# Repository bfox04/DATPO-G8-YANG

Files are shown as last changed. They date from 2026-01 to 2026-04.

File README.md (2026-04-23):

# DATPO — Dual Airfoil Test Platform Octopus (Group 8, Yang)

Capstone project. A motorized dual-airfoil rig for wind tunnel testing, controlled over USB or Bluetooth serial with a browser-based GUI. Controls stagger (X), gap (Y), and angle of attack (ZA bot, ZB top) for both airfoils independently.

---

## Hardware

**Controller:** BTT Octopus V1.0 (STM32F446, 180MHz)

**Motors:** 8× NEMA 17 steppers (17HS19-2004D-E1K, 2A, 1.8°/step)
**Drivers:** TMC2209 in step/dir mode, 8 microsteps

| Axis | Motors | Pitch / Ratio | Limit |
|---|---|---|---|
| X (stagger) | M0, M1 | 5mm/rev | ±415mm |
| Y (gap) | M2–M5 | 2mm/rev | ±225mm |
| ZA (AoA bot)| M6 | 5.1975× gear ratio | ±20° |
| ZB (AoA top)| M7 | 5.1975× gear ratio | ±20° |

**Encoders:** 4× quadrature encoders (1000 PPR / 4000 CPR) on E0–E3, covering X left/right and Y left/right. Used for sync checking only — not closed-loop. E6/E7 slots in the GUI mirror ZA/ZB (see Known Issues).

**Fan:** PA8, on by default, toggle with `FAN` command.

---

## Firmware

Built with PlatformIO (Arduino framework). Source is `FIRMWARE/src/WORKING_MAIN.cpp`.

**You'll need:**
- VS Code + PlatformIO extension
- Serial Monitor extension (or use the GUI)
- Target board: `btt_octopus_f446`

**Key behaviors:**
- Accepts commands over USB (`Serial`) or Bluetooth (`Serial1`, 115200 baud both)
- Broadcasts `POS:` telemetry lines after every move and on `POSITIONS` — this is what the GUI parses
- X and Y encoder pairs are compared each loop cycle; if divergence exceeds 5mm, all motors stop and it auto-enters jog mode for realignment
- Motion is open-loop for ZA/ZB (no encoder feedback on AoA axes)

---

## GUI

`GUI/ENCODER_GUI.html` — open in Chrome, uses Web Serial API. No install needed.

`GUI/WORKING_GUI.html` is the older version, kept for reference.

---

## Serial Command Reference

| Command | Description |
|---|---|
| `X[mm]` | Move X axis to position (e.g. `X50`) |
| `Y[mm]` | Move Y axis to position |
| `ZA[deg]` | Move AoA bot to angle (e.g. `ZA-5`) |
| `ZB[deg]` | Move AoA top to angle |
| `HOME` | Move all axes to zero |
| `POSITIONS` | Print current positions + POS: line |
| `ZERO` | Enter jog & zero mode |
| `ESTOP` | Immediate stop, clears alarm |
| `RESUME` | Clear sync alarm |
| `FAN` | Toggle fan |
| `COMMANDS` | Print command list |

**In jog/zero mode:** `X+` `X-` `Y+` `Y-` `YL+` `YL-` `YR+` `YR-` `ZA+` `ZA-` `ZB+` `ZB-`, individual motors `M0+` through `M7+/-`, `STEP[size]` (0.1/0.25/0.5/1.0/2.0/3.0), `SET` to zero, `EXIT` to leave.

---

## Known Issues & Lessons Learned

**AMT25 absolute encoders on ZA/ZB were attempted and abandoned.** The hardware and firmware implementation were correct, but we got unbeatable EMI from the motor cabling corrupting the encoder signal. The DIAG pins on the Octopus (used as encoder inputs) are physically adjacent to motor driver lines — not great for signal integrity.

**Encoder sync alarm is functional but conservative.** 5mm threshold works well in practice. If you're getting nuisance trips, check that encoder cables are routed away from motor wiring.

**ZA/ZB home angles are not set.** `ZA_HOME_ANGLE` and `ZB_HOME_ANGLE` in firmware are both 0.0 — the rig assumes the airfoils start at 0° on power-up. If you add hard stops, measure and set these.

---

## TODO (Next Group)

- [ ] **Integrate AMT25 absolute encoders on ZA/ZB** — the big one. Hardware and firmware were working; the blocker was EMI. Suggested approach: use shielded cable for encoder lines, route far from motor cabling, or add an external encoder interface board to put distance between the noisy motor drivers and the encoder signal path. The AMT25 uses SSI/SPI — an isolator IC between the Octopus and encoders would likely fix it. This would give true closed-loop AoA control, which is the main thing missing.
- [ ] Measure and set physical hard-stop home angles for ZA/ZB in firmware
- [ ] Add software travel limits as a safety net (currently relies on operator not sending out-of-range commands)
- [ ] Y axis has 4 motors (M2–M5) but only 2 encoders — E2 and E3 cover left and right sides. Consider adding encoders on the far pair if racking becomes an issue.

---

## Repo Layout

```
DATPO-G8-YANG/
├── FIRMWARE/       main firmware (PlatformIO project)
├── GUI/            browser-based serial GUI (Chrome)
├── CAD/            airfoil and zero-tool 3D files
├── DOCS/           manuals, datasheets, master reference, capstone poster
├── PINOUTS/        board and driver pinout images
├── MEDIA/          demo videos
├── ARCHIVE/        old firmware builds
└── TODO.txt        running notes
```

Full consolidated hardware reference (board pinout, driver config, motor specs) is in `DOCS/PROJECT_MASTER_REFERENCE.md`.

Claude was used as a major assistant for writing software.

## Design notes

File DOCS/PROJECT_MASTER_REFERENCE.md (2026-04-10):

# Project Master Reference Document
## Consolidated from: Board Pinout, Board Manual, TMC2209 Pinout, TMC2209 Manual, Motor/Encoder Datasheet

---

# 1. BTT OCTOPUS V1.0 — MOTOR DRIVER PIN MAPPING

| Driver | EN | STEP | DIR  | CS |
|---|---|---|---|---|
| DRIVER0  | PF14 | PF13 | PF12 | PC4  |
| DRIVER1  | PF15 | PG0  | PG1  | PD11 |
| DRIVER2  | PG5  | PF11 | PG3  | PC6  |
| DRIVER3  | PA0  | PG4  | PC1  | PC7  |
| DRIVER4  | PG2  | PF9  | PF10 | PF2  |
| DRIVER5  | PF1  | PC13 | PF0  | PE4  |
| DRIVER6  | PD4  | PE2  | PE3  | PE1  |
| DRIVER7  | PE0  | PE6  | PA14 | PD3  |

Motor-SPI Bus:
- MOSI: PA7
- MISO: PA6
- SCK: PA5

---

# 2. BTT OCTOPUS V1.0 — FULL BOARD PINOUT

## Heaters
| Heater | Voltage | Signal Pin |
|---|---|---|
| HE0 | 24V | PA2 |
| HE1 | 24V | PA3 |
| HE2 | 24V | PB10 |
| HE3 | 24V | PB11 |

## Bed Heater
- BED Power: VBI / GND
- BED-OUT: VBO / PA1

## Temperature Sensors
| Sensor | GND | Signal |
|---|-----|---|
| TB | GND | PF3 |
| T0 | GND | PF4 |
| T1 | GND | PF5 |
| T2 | GND | PF6 |
| T3 | GND | PF7 |

## Fans (PWM)
| Fan | Voltage Pin | Signal Pin |
|---|---|---|
| FAN0  | VFAN0 | PA8 |
| FAN1  | VFAN1 | PE5 |
| FAN2  | VFAN2 | PD12 |
| FAN3  | VFAN3 | PD13 |
| FAN4  | VFAN4 | PD14 |
| FAN5  | VFAN5 | PD15 |
| FAN6  | VFAN6 | GND (always on) |
| FAN7  | VFAN7 | GND (always on) |

Fan voltage selectable per fan: Vin (24V), 12V, or 5V via jumpers.

## DIAG Pins (StallGuard)
| DIAG  | 5V  | GND | Signal |
|---|-----|-----|---|
| DIAG0 | 5V  | GND | PG6 |
| DIAG1 | 5V  | GND | PG9 |
| DIAG2 | 5V  | GND | PG10 |
| DIAG3 | 5V  | GND | PG11 |
| DIAG4 | 5V  | GND | PG12 |
| DIAG5 | 5V  | GND | PG13 |
| DIAG6 | 5V  | GND | PG14 |
| DIAG7 | 5V  | GND | PG15 |

## I2C & EEPROM
- SCL: PB8
- SDA: PB9
- Onboard 32K EEPROM (AT24C32)

## SPI Expansion Header
- 3.3V, PB5 (MOSI), PA15 (CS), PB4 (MISO), PB3 (SCK), GND

## USB-A Port
- GND, PB15, PB14, 5V

## Raspberry Pi Header
- 5V, GND (multiple), PD6(RX), PD5(TX), 5V

## TFT Header
- RST, PA10(RX), PA9(TX), GND, 5V

## BL Touch Header
- GND, 5V, PB6, PB7, GND

## EXP1 (Display)
- PE8, PE9, PE12, PE14, GND
- PE7, PE10, PE13, PE15, 5V

## EXP2 (Display)
- PA6, PB1, PB2, PC15, RST
- PA5, PA4, PA7, GND, PC5

## PS ON (Power Supply Control)
- PE11, GND

## SENSOR (Probe)
- VS, GND, PB7

## CAN Bus (RJ11)
- NC, CAN_L, CAN_H, NC
- RX: PD0, TX: PD1

## SDIO-MicroSD
- D0: PC8, D1: PC9, D2: PC10, D3: PC11, CLK: PC12, DET: PC14, CMD: PD2

## SPI3 Expansion Header
Row 1: 3.3V, PC3, PC2, PB13, NC, PG8, NC, PG7 (MOSI, MISO, SCK)
Row 2: GND, PB12, NC, PD7, PD10, NC, PD8, PD9 (CS, TX, RX)

## RGB LED
- GND, PB0, 5V

## PT100 Interface
- PF8, PT100_P, PT100_N

## Power Detection
- PWR-DET: 3.3V, GND, PC0

---

# 3. BTT OCTOPUS V1.0 — BOARD MANUAL SUMMARY

## Key Specs
- MCU: STM32F446ZET6 (ARM Cortex-M4, 180MHz)
- Board size: 160mm x 100mm (mounting holes: 150mm x 90mm)
- Supports Klipper and Marlin firmware
- Recommended input: DC 24V (12V supported on motor and bed rails only; logic must be >14.1V)
- Built-in regulators: 12V (4A), 5V (8A), 3.3V (1A)
- Up to 8 stepper drivers, 9 stepper outputs (MOTOR2 has dual output for parallel Z)
- 4 hotend heaters, 1 heated bed (up to 300W, use external MOSFET for higher)
- 6 PWM fans + 2 always-on fans, individually voltage-selectable (Vin/12V/5V)
- Flyback protection on all PWM fan ports
- 6 endstop inputs, 2 filament runout inputs
- USB-C (virtual serial), UART, SPI connections to Raspberry Pi
- Onboard 32K EEPROM (AT24C32)
- BL Touch support, dedicated PROBE port (optocoupler-protected, no BAT85 needed)
- CAN Bus via RJ11 (6P6C)
- StallGuard support for sensorless homing (TMC drivers)
- SPI expansion port (for MAX31865, etc.)
- DIY PT100 interface (requires user-soldered INA826AIDR amplifier, SOP-8)
- Thermistor inputs protected up to Vin; unused inputs usable as GPIO
- WiFi interface for ESP8266 modules
- RGB LED interface
- SD card firmware update (firmware.bin → FIRMWARE.CUR)
- Supports DFU mode firmware update (overwrites bootloader — not recommended for novices)

## Power Wiring
Three separate power inputs (common ground):
1. Motherboard power (must be >14.1V for logic regulators)
2. Motor power (12V or 24V)
3. Bed heater power (12V or 24V)

## Stepper Driver Modes

### Step/Dir Mode
Jumper layout beneath each driver (simplified):
```
Row 1 (top):    0V     0V     0V     0V
Row 2 (middle): RST    MS3/2  MS2/1  MS1/0
Row 3 (bottom): SLP    3.3V   3.3V   3.3V
```
- Jumper top-to-middle: sets MS pin to 0V (LOW)
- Jumper middle-to-bottom: sets MS pin to 3.3V (HIGH)
- First column: connects SLP to RST (required for A4988/DRV8825)
- Note: Using non-16 microstepping in step/dir mode prevents SPI mode on other drivers (shared pins)

### UART Mode
Single jumper on the designated UART position beneath the driver.

### SPI Mode
Specific jumper configuration beneath the driver for SPI communication.

## StallGuard / Sensorless Homing
DIAG jumpers connect driver diagnostic output to endstop inputs. Located in a dedicated jumper block on the board.

## Probe Port
- Internally protected via optocoupler (no BAT85 diode needed)
- NPN probes: add external 4K7 pull-up between probe V+ and signal
- PNP probes: connect directly
- Must enable internal pull-down resistor on probe input pin in firmware

## Klipper Firmware Settings
When compiling Klipper, use settings to preserve factory bootloader:
- Micro-controller: STM32
- Processor: STM32F446
- Bootloader offset: 32KiB
- Communication: USB on PA11/PA12

## Precautions
1. Never work on board with power applied
2. Double-check all jumpers/wiring before powering on
3. Heated bed max 300W (use external MOSFET for more)
4. Always reference PINS.pdf for connections
5. SD card firmware update recommended over DFU
6. Early production silkscreen errors on: Fan polarity, SPI3 header, Raspberry Pi UART header

---

# 4. BIGTREETECH TMC2209 V1.2 — SCHEMATIC/PINOUT

## IC Pin Connections (TMC2209 chip — U1)
| Pin # | Name | Function |
|---|---|---|
| 2 | ENN | Enable (active low) |
| 16 | STEP | Step pulse input |
| 19 | DIR | Direction input |
| 11 | DIAG | Diagnostic/StallGuard output |
| 12 | INDEX | Configurable index output |
| 9 | MS1 | Microstep config / UART addr |
| 10 | MS2 | Microstep config / UART addr |
| 9 | MS1_AD0 | Address bit 0 (UART mode) |
| 10 | MS2_AD1 | Address bit 1 (UART mode) |
| 13 | CLK | Clock input |
| 14 | PDN_UART  | UART interface |
| 17 | VREF | Analog reference for current |
| 15 | VCC_IO | Logic supply voltage |
| 8 | 5VOUT | Internal 5V regulator output |
| 22 | VS | Motor supply voltage |
| 28 | VS | Motor supply voltage |
| 6 | VCP | Charge pump capacitor |
| 5 | CPI | Charge pump input |
| 4 | CPO | Charge pump output |
| 1 | OB2 | Output bridge B2 |
| 26 | OB1 | Output bridge B1 |
| 24 | OA2 | Output bridge A2 |
| 21 | OA1 | Output bridge A1 |
| 23 | BRA | Bridge sense resistor A |
| 27 | BRB | Bridge sense resistor B |
| 7 | SPREAD | SpreadCycle/StealthChop select |
| 20 | STDBY | Standby |

## Module Connector Pinout (J1 and J2 headers on module)
### J1 (Left side, active pins):
| Pin | Name | Function |
|-----|---|---|
| 1 | EN | Enable |
| 2 | MS1 | Microstep setting |
| 3 | MS2 | Microstep setting |
| 4 | PDN_UART | UART communication  |
| 5 | PDN_UART | UART communication  |
| 6 | CLK | Clock |
| 7 | STEP | Step pulse input |
| 8 | DIR | Direction input |

### J2 (Right side, motor/power):
| Pin | Name | Function |
|-----|---|---|
| 1 | VM | Motor voltage |
| 2 | GND | Ground |
| 3 | A2 | Motor Phase A |
| 4 | A1 | Motor Phase A |
| 5 | B1 | Motor Phase B |
| 6 | B2 | Motor Phase B |
| 7 | VCC_IO | Logic voltage |
| 8 | GND | Ground |

### Additional Module Pins:
- DIAG: Diagnostic/StallGuard output (directly accessible via header)
- VREF: Analog reference (accessible via potentiometer)
- INDEX: Configurable index pulse output

## SPREAD Pin Configuration
| Mode | SPREAD |
|---|---|
| StealthChop | 0 (LOW) |
| SpreadCycle | 1 (HIGH) |

## Microstep Configuration
| MS1 | MS2 | Microstep |
|-----|-----|---|
| 0 | 0 | 1/8 |
| 1 | 0 | 1/2 |
| 0 | 1 | 1/4 |
| 1 | 1 | 1/16 |

Note: MicroPlyer interpolation provides up to 256 microsteps regardless of MS pin setting.

## Vref / Current Setting
- Vref range: 0.2V — 2.2V
- Factory default Vref: 1.2V ±0.1V
- Factory default current: 0.9A
- Clockwise potentiometer rotation: decreases Vref → decreases current
- Counter-clockwise rotation: increases Vref → increases current

## Key External Components (from schematic)
- C2: 100nF/50V (VDD decoupling)
- C5: 4.7nF (GND)
- C1: 1nF/50V, C3/C4: 100nF/50V (VS decoupling)
- C6: 100nF, C7: 22nF/50V (charge pump)
- R1: 20K (EN pull-up)
- R3: 100K (CLK), R4: 100K (PDN_UART)
- R5: (VREF setting)
- R6: 20K, R7: 20K (address resistors)
- 0R11 sense resistors on BRA/BRB

---

# 5. BIGTREETECH TMC2209 V1.2 — DRIVER MODULE MANUAL

## Product Specs
- Continuous drive current: 2A RMS
- Peak current: 2.8A
- Voltage range: 4.75V — 28V DC
- Module size: 15.24mm x 20.32mm
- Operating modes: STEP/DIR or UART
- Microstep settings: 2, 4, 8, 16 (interpolated up to 256)

## Technologies
- SpreadCycle: high-dynamic motor control chopper
- StealthChop2: ultra-quiet operation
- MicroPlyer: microstep interpolation to 256
- StallGuard4: stall/locked-motor detection
- CoolStep: dynamic current control (up to 75% energy savings)

## UART Mode Setup
- Factory default: UART connected to pin 4 (PDN_UART on left header)
- To use pin 5 as UART: remove resistor and re-solder to alternate pads

## StealthChop vs SpreadCycle
- Factory default: StealthChop (mute/quiet mode)
- To switch to SpreadCycle (anti-shake mode): remove resistor and re-solder to alternate pads

## Safety Precautions
1. Disconnect power before installing/removing driver
2. Confirm driver orientation before insertion (prevent reverse insertion)
3. Verify wiring sequence and I/O connections
4. Do not hot-swap driver modules
5. Ensure heatsink does not short any pins
6. Handle with ESD precautions
7. Always provide heat dissipation (heatsink + fan recommended)

---

# 6. STEPPER MOTOR — 17HS19-2004D-E1K (StepperOnline)

## Motor Specifications
| Parameter | Value |
|---|---|
| Connection | Bipolar |
| Amps/Phase | 2.00A |
| Resistance/Phase @ 25°C | 1.10Ω ±10% |
| Inductance/Phase @ 1kHz | 1.70mH ±20% |
| Holding Torque | 0.52 Nm [4.60 lb-in] |
| Step Angle | 1.8° |
| Step Accuracy (non-accumulative) | ±5.00% |
| Rotor Inertia | 82.00 g·cm² |
| Weight | 0.50 kg [1.10 lb] |
| Ambient Temperature | -10°C to 50°C [14°F–122°F] |
| Insulation Class | B (130°C / 266°F) |
| Temperature Rise | MAX 80°C |

## Motor Wiring (Bipolar)
| Pin | Bipolar | Lead Color | Winding |
|-----|---|---|---|
| 1 | A+ | BLK (Black)| A+ |
| 2 | A- | GRN (Green)| A- |
| 3 | B+ | RED | B+ |
| 4 | B- | BLU (Blue) | B- |

## Motor Cable
- TRVV 4×0.2² black servo towline cable
- Length: 500±10mm
- Heat shrink tube at motor junction

## Encoder Specifications
- Resolution: 1000 PPR (4000 CPR with quadrature)
- Cable: TRVVP 6×0.15² black shielded wire
- Cable length: 500±10mm

## Encoder Wiring
| Lead Color | Description |
|---|---|
| RED | VCC (power) |
| WHT (White)| GND |
| BLK (Black)| EA+ (Encoder A+) |
| BLU (Blue) | EA- (Encoder A-) |
| YEL (Yellow)| EB+ (Encoder B+) |
| GRN (Green)| EB- (Encoder B-) |

## Mechanical Dimensions (mm)
- Body: 42.3 MAX × 42.3 MAX (NEMA 17)
- Flange: 31±0.1 × 31±0.1
- Mounting holes: 4× M3, depth 4.5mm
- Shaft diameter: Ø5 (0 / -0.012mm tolerance)
- Shaft length: 24±1mm (from flange)
- Total length with encoder: 68±1mm
- Shaft flat: 15±0.2mm from flange, width 2mm
- Rear shaft extension: 9.6mm, width 32mm

## Full Step Sequence (2-phase, facing mounting end)
| Step | A+ | B+ | A- | B- | Direction |
|---|----|----|----|----|---|
| 1 | +  | +  | -  | -  | CCW |
| 2 | -  | +  | +  | -  | ↓ |
| 3 | -  | -  | +  | +  | ↓ |
| 4 | +  | -  | -  | +  | CW |

## Operating Limits
- Dynamic axial load: 10N max
- Dynamic radial load @ shaft 20mm: 21N max
- TMBF: 6000h or more @ 24V/300RPM
- Insulation resistance: 100 MΩ (normal temp/humidity)
- Dielectric strength: 500VAC for 1 min (between coils and case)

---

# 7. APPENDIX — COMMON DRIVER MICROSTEPPING TABLES

## A4988 (max 16 microsteps, 35V 2A)
| MS1 | MS2 | MS3 | Microstep  |
|-----|-----|-----|---|
| L | L | L | Full Step  |
| H | L | L | 1/2 |
| L | H | L | 1/4 |
| H | H | L | 1/8 |
| H | H | H | 1/16 |

Current formula: Imax = Vref / (8 × Rs), Rs = 0.1Ω

## LV8729 (max 128 microsteps, 36V 1.8A)
| MD3 | MD2 | MD1 | Microstep  |
|-----|-----|-----|---|
| L | L | L | Full Step  |
| L | L | H | 1/2 |
| L | H | L | 1/4 |
| L | H | H | 1/8 |
| H | L | L | 1/16 |
| H | L | H | 1/32 |
| H | H | L | 1/64 |
| H | H | H | 1/128 |

Current formula: Iout = (Vref / 5) / Rf1, Rs = 0.22Ω

## DRV8825 (max 32 microsteps, 8.2V–45V 2.5A @ 24V T=25°C)
| MODE2 | MODE1 | MODE0 | Microstep  |
|---|---|---|---|
| L | L | L | Full Step  |
| L | L | H | 1/2 |
| L | H | L | 1/4 |
| L | H | H | 1/8 |
| H | L | L | 1/16 |
| H | L | H | 1/32 |
| H | H | L | 1/32 |
| H | H | H | 1/32 |

Current formula: I_CHOP = V_REFX / (5 × R_ISENSE), Rs = 0.1Ω

## TMC2209 (on module, for reference)
| MS1 | MS2 | Microstep |
|-----|-----|---|
| 0 | 0 | 1/8 |
| 1 | 0 | 1/2 |
| 0 | 1 | 1/4 |
| 1 | 1 | 1/16 |

All modes interpolated to 256 microsteps via MicroPlyer.

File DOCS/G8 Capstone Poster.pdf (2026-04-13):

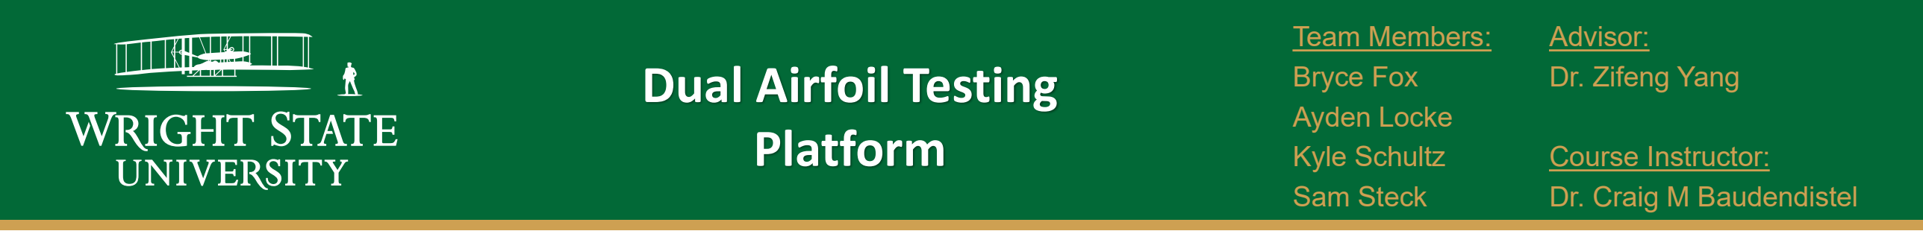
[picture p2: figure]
Dual Airfoil Testing Platform; Team Members:; Bryce Fox; Ayden Locke; Kyle Schultz; Sam Steck; Advisor:; Dr. Zifeng Yang; Course Instructor:; Dr. Craig M Baudendistel
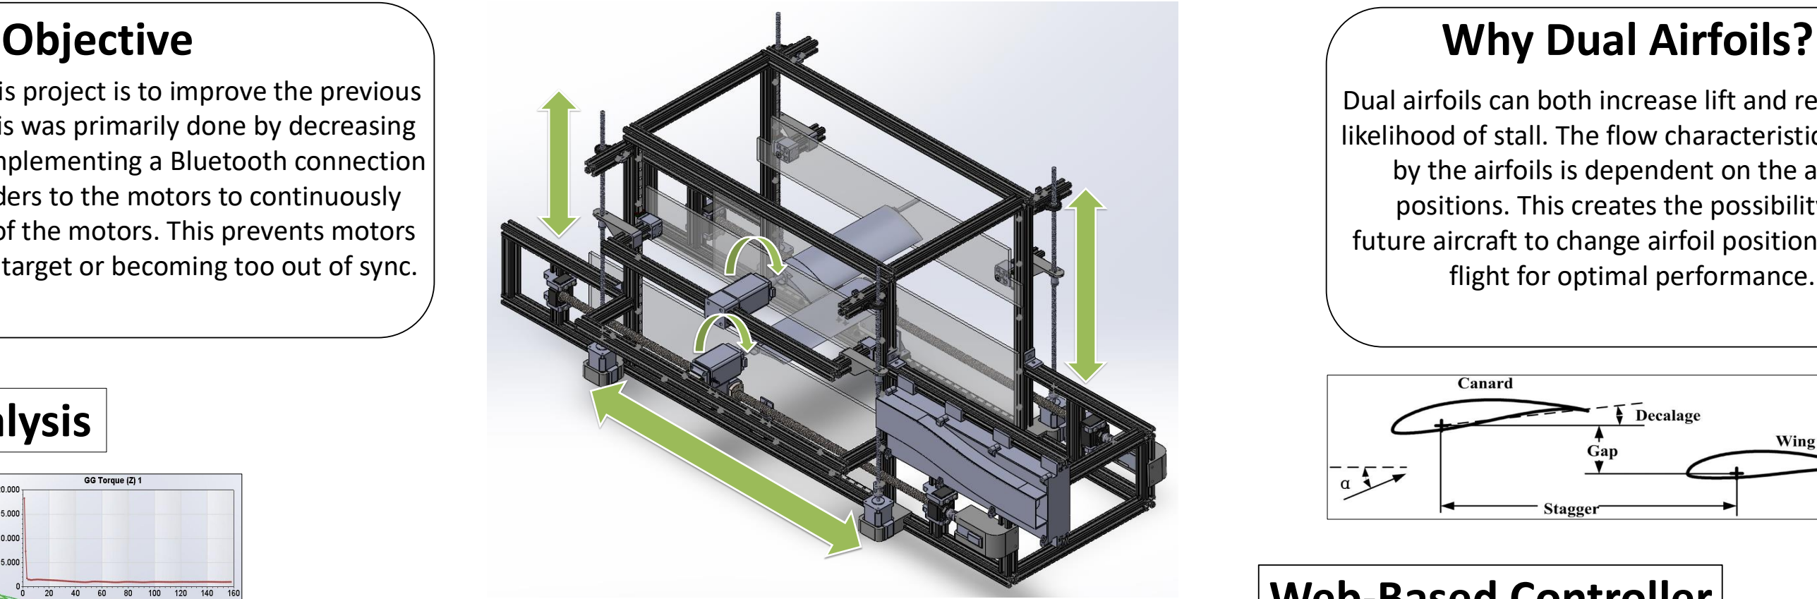
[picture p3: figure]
Objective; Why Dual Airfoils?; flight for optimal performance.

The objective of this project is to improve the previous group's design. This was primarily done by decreasing the lose wires by implementing a Bluetooth connection and adding encoders to the motors to continuously read the position of the motors. This prevents motors from missing their target or becoming too out of sync.

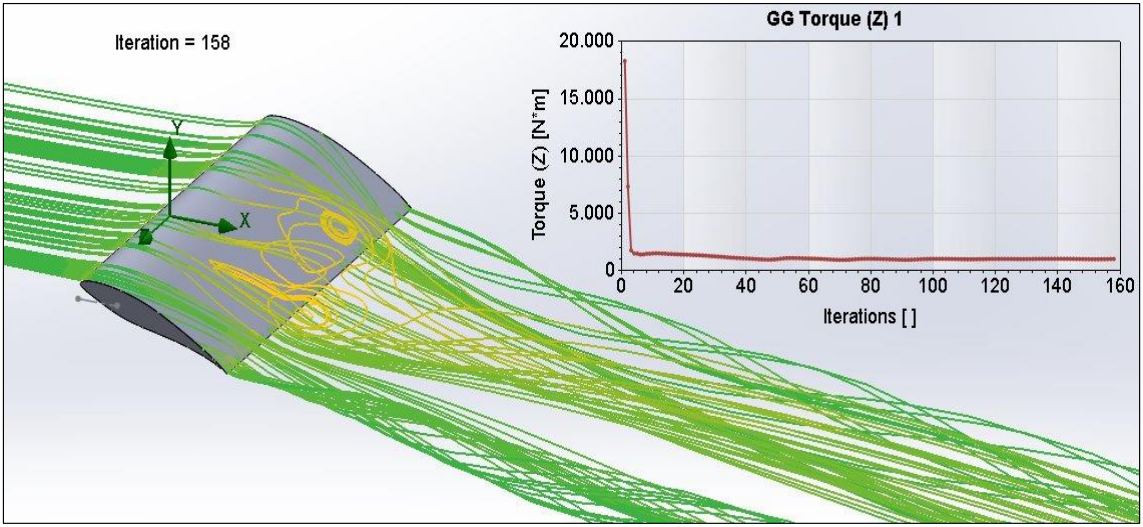
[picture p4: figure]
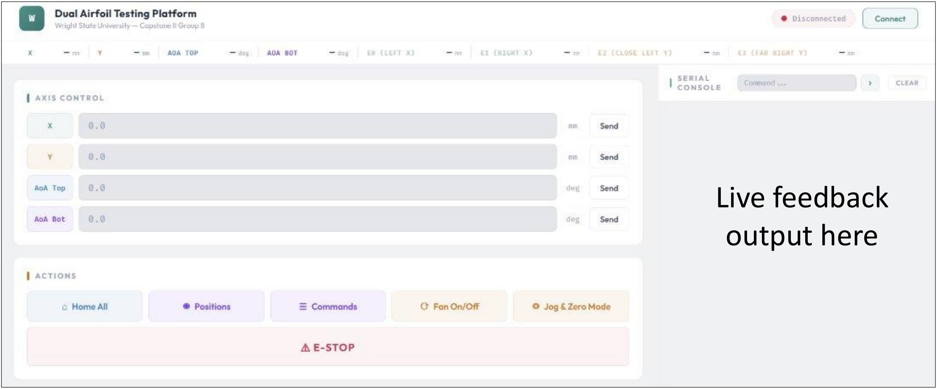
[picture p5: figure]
Live feedback output here

## Flow Visualization

Dual airfoils can both increase lift and reduce the likelihood of stall. The flow characteristics caused by the airfoils is dependent on the airfoil positions. This creates the possibility for future aircraft to change airfoil positions during

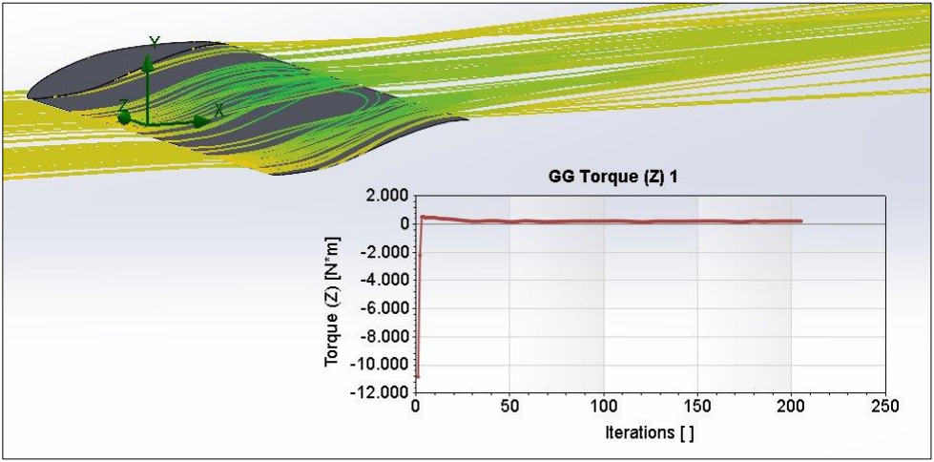
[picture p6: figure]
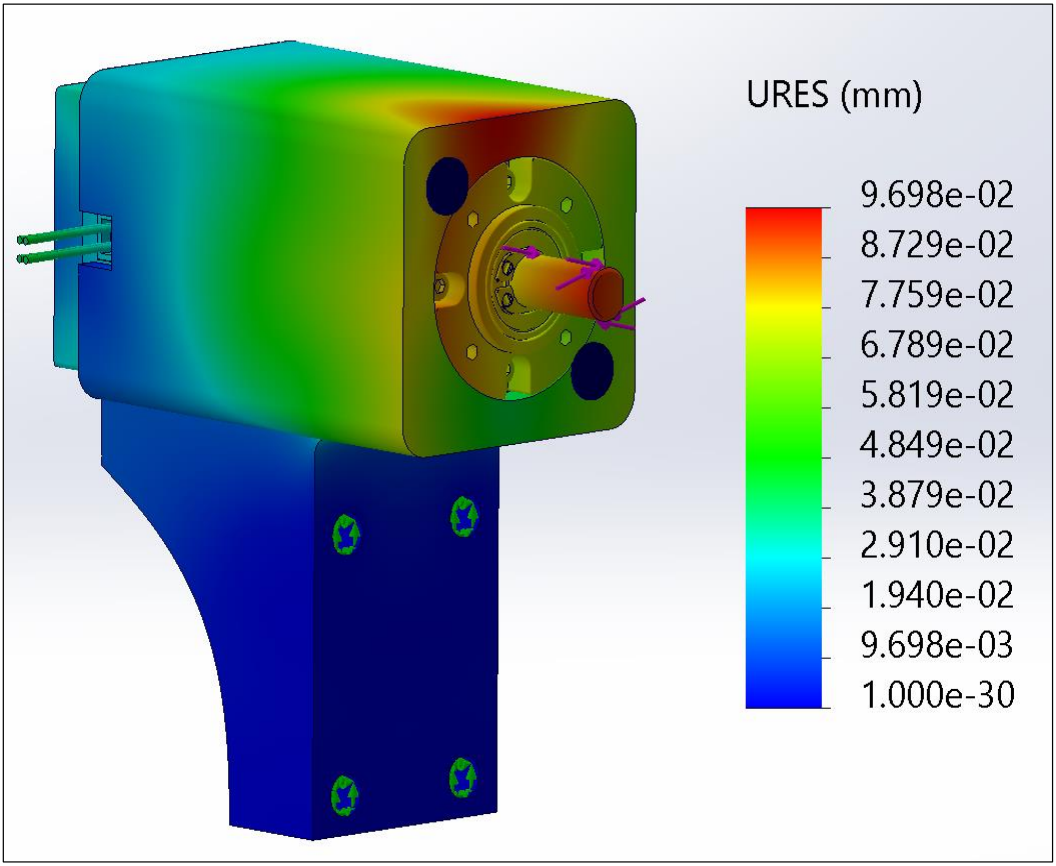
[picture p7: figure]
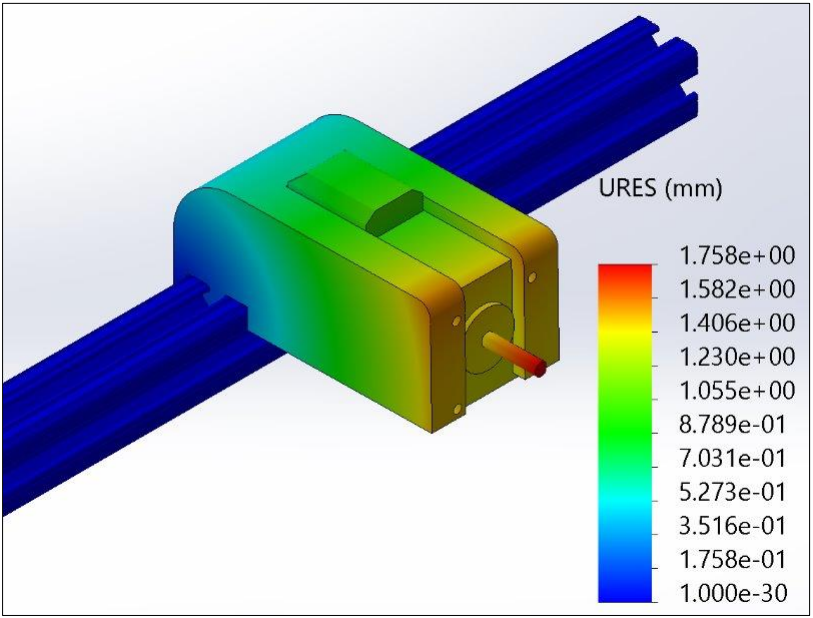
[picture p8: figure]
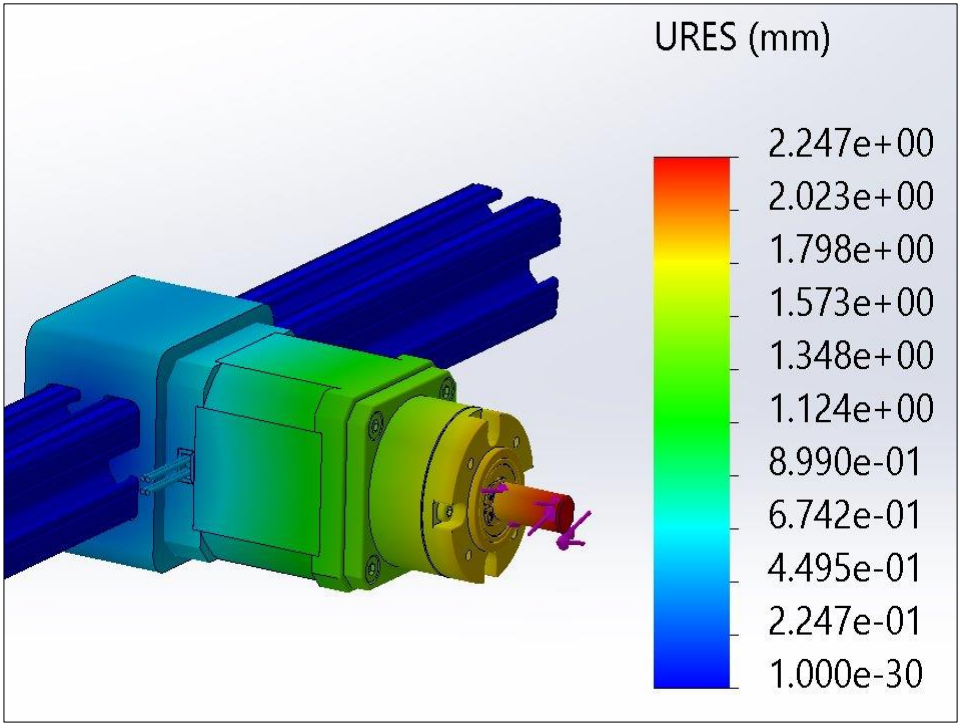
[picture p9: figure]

## FEA

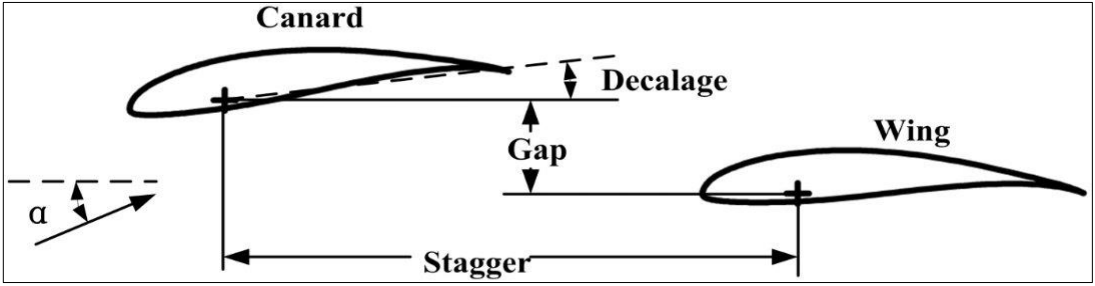
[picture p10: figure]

## CFD Analysis

FEA was performed to confirm that our new motor mounts would not break or deform under the loading. A CFD analysis was also performed to verify the amount of torque the motors needed to withstand under wind tunnel testing.

## Web-Based Controller

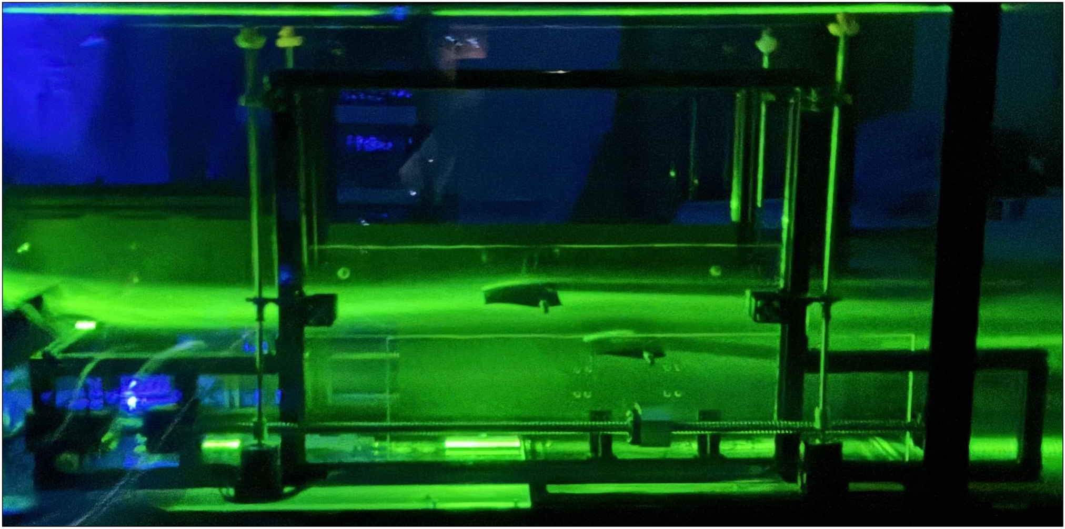
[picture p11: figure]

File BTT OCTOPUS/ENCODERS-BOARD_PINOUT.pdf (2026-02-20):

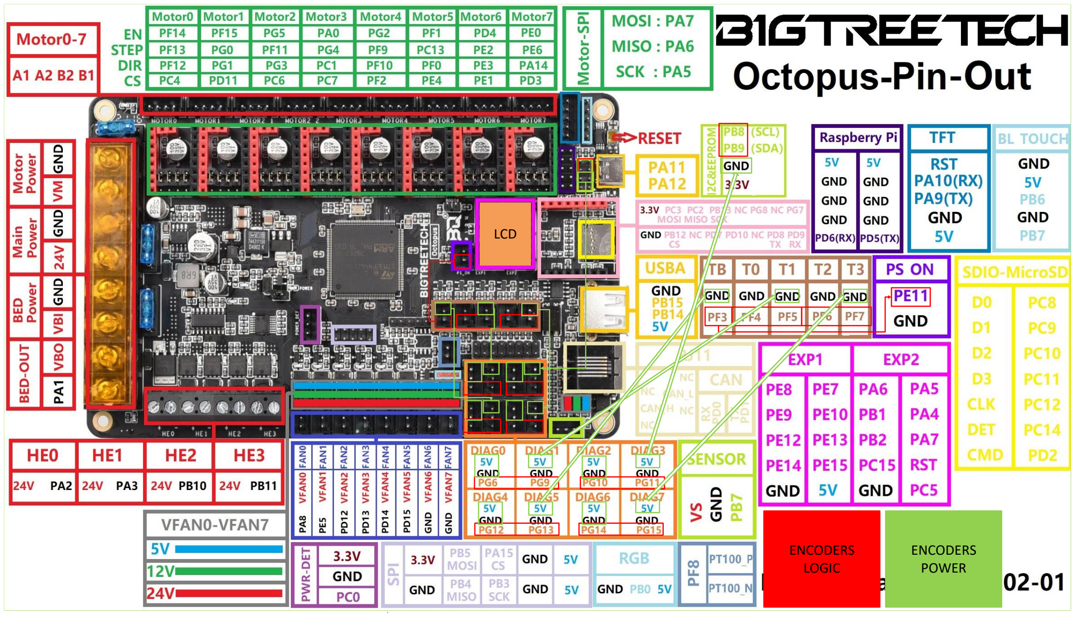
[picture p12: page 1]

z

`

` | ` | `

`

ENCODERS
LOGIC

`

` | `

`

`

`

` | `
` | `

`
`

LCD

`

ENCODERS
POWER

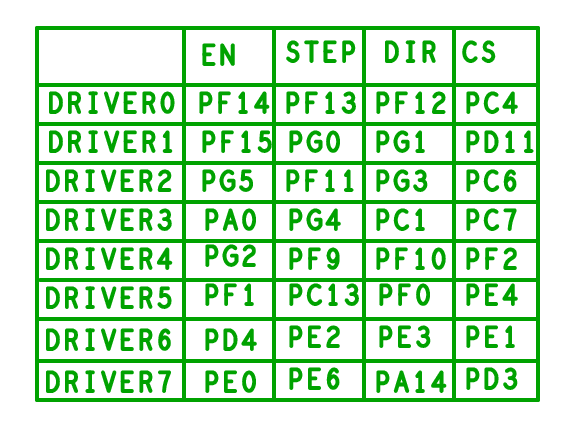
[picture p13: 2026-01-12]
PINOUTS/board_motor_driver_pins.png

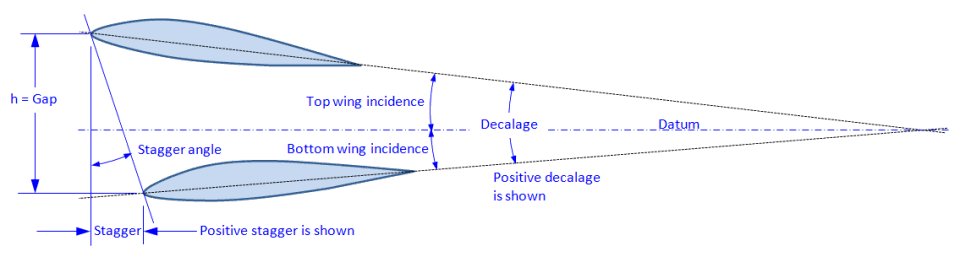
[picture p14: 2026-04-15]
PINOUTS/airfoil_values_example.jpg

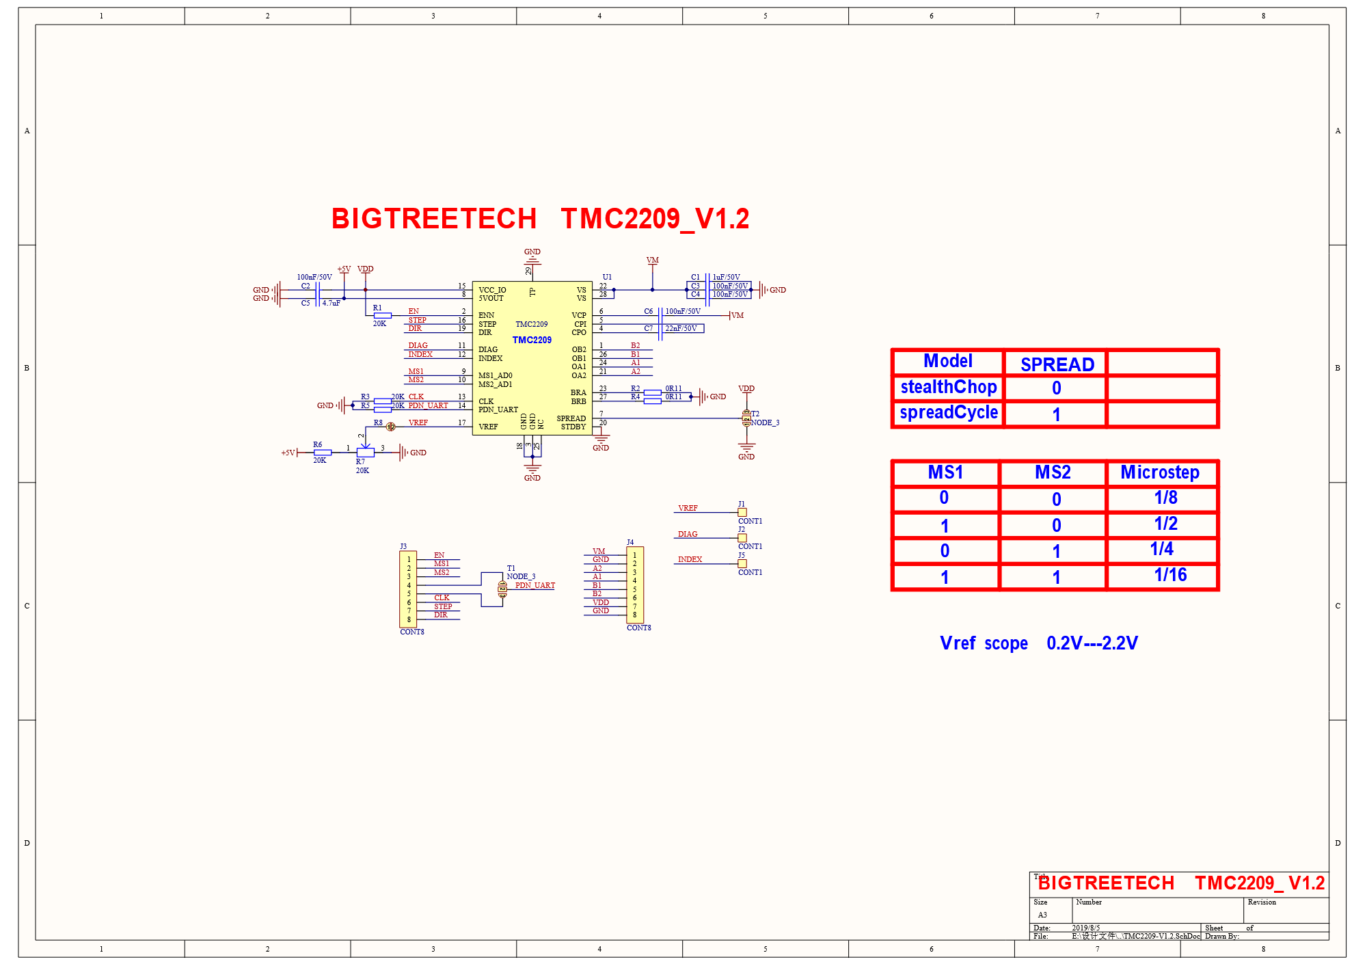
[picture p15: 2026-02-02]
PINOUTS/TMC2209_PINOUT.png

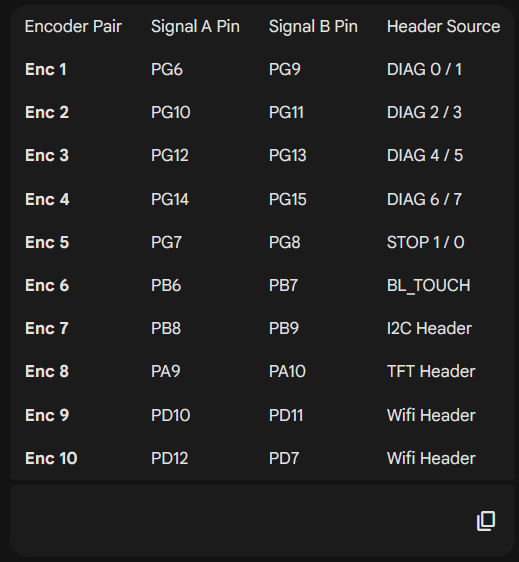
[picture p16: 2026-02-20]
BTT OCTOPUS/encoder_pins_plan.png

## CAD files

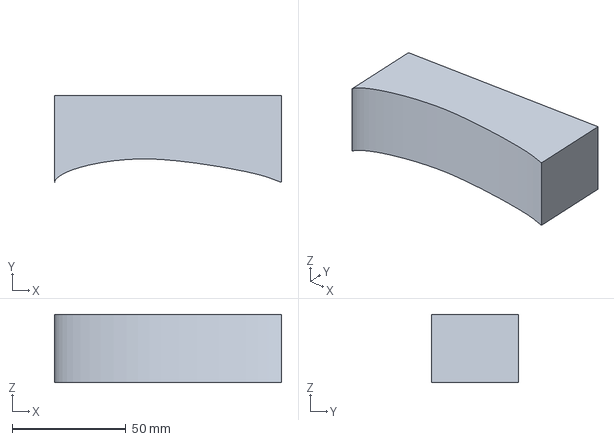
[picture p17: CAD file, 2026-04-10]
CAD/Airfoil 2.3MF
100.0 x 38.2 x 30.0 mm

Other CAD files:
CAD/zero-tool.SLDPRT
CAD/Airfoil 2.STL

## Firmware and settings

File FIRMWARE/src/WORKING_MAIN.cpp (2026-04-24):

#include <Arduino.h>
#include <AccelStepper.h>

// motor pin defs

//m0
#define ENABLE_PIN0 PF14
#define STEP_PIN0   PF13
#define DIR_PIN0    PF12

//m1
#define ENABLE_PIN1 PF15
#define STEP_PIN1   PG0
#define DIR_PIN1    PG1

//m2
#define ENABLE_PIN2 PG5
#define STEP_PIN2   PF11
#define DIR_PIN2    PG3

//m3
#define ENABLE_PIN3 PA0
#define STEP_PIN3   PG4
#define DIR_PIN3    PC1

//m4
#define ENABLE_PIN4 PG2
#define STEP_PIN4   PF9
#define DIR_PIN4    PF10

//m5
#define ENABLE_PIN5 PF1
#define STEP_PIN5   PC13
#define DIR_PIN5    PF0

//m6
#define ENABLE_PIN6 PD4
#define STEP_PIN6   PE2
#define DIR_PIN6    PE3

//m7
#define ENABLE_PIN7 PE0
#define STEP_PIN7   PE6
#define DIR_PIN7    PA14

// encoder pin defs

//E0 — X left (M0)
#define EB0plus     PG6
#define EA0plus     PG9

//E1 — X right (M1)
#define EB1plus     PG10
#define EA1plus     PG11

//E2 — Y rear left (M2)
#define EB2plus     PG12
#define EA2plus     PG13

//E3 — Y left far, EXP1 (new)
#define EB3plus     PE8
#define EA3plus     PE7

//E4 — Y right close, EXP1 (new)
#define EB4plus     PE9
#define EA4plus     PE10

//E5 — Y right far (M5)
#define EB5plus     PG14
#define EA5plus     PG15

// fan
#define FAN0_PIN    PA8
bool fanOn = true;

const float PULSES_PER_REV = 2000.0;
volatile long encoder0Ticks = 0;
volatile long encoder1Ticks = 0;
volatile long encoder2Ticks = 0;
volatile long encoder3Ticks = 0;
volatile long encoder4Ticks = 0;
volatile long encoder5Ticks = 0;

// sync alarm thresholds
const float X_SYNC_THRESHOLD_MM = 5.0;
const float Y_SYNC_THRESHOLD_MM = 5.0;
bool syncAlarm = false;
String alarmSource = "";  // which axis tripped: "X" or "Y"

// motion config
const int MICROSTEP_SETTING = 8;
const long STEPS_PER_REV = 200 * MICROSTEP_SETTING;
const float X_PITCH = 5.0;
const float Y_PITCH = 2.0;
const float ZA_GEAR_RATIO = 5.197539843600339;
const float ZB_GEAR_RATIO = 5.197539843600339;

// home angles — physical stop position on power-up, 0.0 if no hard stop
const float ZA_HOME_ANGLE = 0.0;  // TODO: measure and set
const float ZB_HOME_ANGLE = 0.0;  // TODO: measure and set

// jog/zero mode state
bool zeroingMode = false;
float jogStepMM  = 0.25;  // set at runtime via STEP command
float jogStepDeg = 0.25;

long getJogStepsX()  { return max(1L, lround((jogStepMM  / X_PITCH)  * STEPS_PER_REV)); }
long getJogStepsY()  { return max(1L, lround((jogStepMM  / Y_PITCH)  * STEPS_PER_REV)); }
long getJogStepsZA() { return max(1L, lround((jogStepDeg * ZA_GEAR_RATIO / 360.0) * STEPS_PER_REV)); }
long getJogStepsZB() { return max(1L, lround((jogStepDeg * ZB_GEAR_RATIO / 360.0) * STEPS_PER_REV)); }

// steppers
AccelStepper steppers[] = {
    AccelStepper(AccelStepper::DRIVER, STEP_PIN0, DIR_PIN0),
    AccelStepper(AccelStepper::DRIVER, STEP_PIN1, DIR_PIN1),
    AccelStepper(AccelStepper::DRIVER, STEP_PIN2, DIR_PIN2),
    AccelStepper(AccelStepper::DRIVER, STEP_PIN3, DIR_PIN3),
    AccelStepper(AccelStepper::DRIVER, STEP_PIN4, DIR_PIN4),
    AccelStepper(AccelStepper::DRIVER, STEP_PIN5, DIR_PIN5),
    AccelStepper(AccelStepper::DRIVER, STEP_PIN6, DIR_PIN6),
    AccelStepper(AccelStepper::DRIVER, STEP_PIN7, DIR_PIN7)
};

const int numMotors = 8;
int enPins[] = {ENABLE_PIN0, ENABLE_PIN1, ENABLE_PIN2, ENABLE_PIN3, ENABLE_PIN4, ENABLE_PIN5, ENABLE_PIN6, ENABLE_PIN7};

enum InputSource { SOURCE_NONE, SOURCE_USB, SOURCE_BT };
InputSource lastSource = SOURCE_NONE;

// encoder ISRs
void handleEncoder0() {
    if (digitalRead(EA0plus) == digitalRead(EB0plus)) encoder0Ticks++; else encoder0Ticks--;
}
void handleEncoder1() {
    if (digitalRead(EA1plus) == digitalRead(EB1plus)) encoder1Ticks++; else encoder1Ticks--;
}
void handleEncoder2() {
    if (digitalRead(EA2plus) == digitalRead(EB2plus)) encoder2Ticks++; else encoder2Ticks--;
}
void handleEncoder3() {
    if (digitalRead(EA3plus) == digitalRead(EB3plus)) encoder3Ticks++; else encoder3Ticks--;
}
void handleEncoder4() {
    if (digitalRead(EA4plus) == digitalRead(EB4plus)) encoder4Ticks++; else encoder4Ticks--;
}
void handleEncoder5() {
    if (digitalRead(EA5plus) == digitalRead(EB5plus)) encoder5Ticks++; else encoder5Ticks--;
}

void sendResponse(const String& msg, InputSource source) {
    if (source == SOURCE_USB || source == SOURCE_NONE) Serial.println(msg);
    if (source == SOURCE_BT || source == SOURCE_NONE) Serial1.println(msg);
}

// encoder ticks → mm
float encoderMM_X(volatile long &ticks) {
    return (static_cast<float>(ticks) / PULSES_PER_REV) * X_PITCH;
}
float encoderMM_Y(volatile long &ticks) {
    return (static_cast<float>(ticks) / PULSES_PER_REV) * Y_PITCH;
}

// steps → real units
float stepsToMM_X(long steps) {
    return (static_cast<float>(steps) / STEPS_PER_REV) * X_PITCH;
}
float stepsToMM_Y(long steps) {
    return (static_cast<float>(steps) / STEPS_PER_REV) * Y_PITCH;
}
float stepsToDeg_Z(long steps, float gearRatio) {
    return (static_cast<float>(steps) / STEPS_PER_REV) * 360.0 / gearRatio;
}

// any motor still running?
bool anyMotorMoving() {
    for (int i = 0; i < numMotors; i++) {
        if (steppers[i].distanceToGo() != 0) return true;
    }
    return false;
}

// send POS: line to GUI
// Format: POS:X=12.50,Y=6.25,ZA=15.00,ZB=-3.00,E0=12.48,E1=12.52,E2=6.20,E3=6.22,E4=6.21,E5=6.23
void sendPositionUpdate(InputSource source) {
    float xMM  = stepsToMM_X(steppers[0].currentPosition());
    float yMM  = stepsToMM_Y(steppers[2].currentPosition());
    float zaDeg = stepsToDeg_Z(steppers[6].currentPosition(), ZA_GEAR_RATIO);
    float zbDeg = stepsToDeg_Z(steppers[7].currentPosition(), ZB_GEAR_RATIO);
    float e0mm = encoderMM_X(encoder0Ticks);
    float e1mm = encoderMM_X(encoder1Ticks);
    float e2mm = encoderMM_Y(encoder2Ticks);
    float e3mm = encoderMM_Y(encoder3Ticks);
    float e4mm = encoderMM_Y(encoder4Ticks);
    float e5mm = encoderMM_Y(encoder5Ticks);

    String pos = "POS:X=" + String(xMM, 2)
            + ",Y=" + String(yMM, 2)
            + ",ZA=" + String(zaDeg, 2)
            + ",ZB=" + String(zbDeg, 2)
            + ",E0=" + String(e0mm, 2)
            + ",E1=" + String(e1mm, 2)
            + ",E2=" + String(e2mm, 2)
            + ",E3=" + String(e3mm, 2)
            + ",E4=" + String(e4mm, 2)
            + ",E5=" + String(e5mm, 2);
    sendResponse(pos, source);
}

// motor pos as formatted string
String motorPosStr(int mNum) {
    // use target since move() is relative
    long target = steppers[mNum].targetPosition();
    if (mNum <= 1) return String(stepsToMM_X(target), 2) + "mm";
    else if (mNum <= 5) return String(stepsToMM_Y(target), 2) + "mm";
    else return String(stepsToDeg_Z(target, (mNum == 6) ? ZA_GEAR_RATIO : ZB_GEAR_RATIO), 2) + "deg";
}

void processCommand(String input, InputSource source) {
    input.trim();
    input.toUpperCase();

    // always available
    if (input == "ESTOP") {
        for(int i = 0; i < numMotors; i++) {
            steppers[i].stop();
            steppers[i].setCurrentPosition(steppers[i].currentPosition());
        }
        syncAlarm = false;
        if (zeroingMode) { zeroingMode = false; sendResponse(">> E-STOPPED — Exited jog & zero mode", source); }
        else { sendResponse(">> E-STOPPED", source); }
        sendPositionUpdate(source);
        return;
    }
    if (input == "FAN") {
        fanOn = !fanOn;
        digitalWrite(FAN0_PIN, fanOn ? HIGH : LOW);
        sendResponse(fanOn ? ">> Fan ON" : ">> Fan OFF", source);
        return;
    }
    if (input == "RESUME") {
        if (syncAlarm) {
            syncAlarm = false;
            sendResponse(">> Alarm cleared. Resuming motion.", source);
        } else {
            sendResponse(">> No alarm active.", source);
        }
        return;
    }

    // human-readable positions + POS: line for GUI
    if (input == "POSITIONS") {
        float xMM   = stepsToMM_X(steppers[0].currentPosition());
        float yMM   = stepsToMM_Y(steppers[2].currentPosition());
        float zaDeg = stepsToDeg_Z(steppers[6].currentPosition(), ZA_GEAR_RATIO);
        float zbDeg = stepsToDeg_Z(steppers[7].currentPosition(), ZB_GEAR_RATIO);

        sendResponse("Positions: X=" + String(xMM, 2) + "mm  Y=" + String(yMM, 2)
                    + "mm  AoA Bot=" + String(zaDeg, 2) + "deg  AoA Top=" + String(zbDeg, 2) + "deg", source);

        // raw steps
        String raw = "Raw steps: ";
        for(int i = 0; i < numMotors; i++) {
            raw += "M" + String(i) + "=" + String(steppers[i].currentPosition()) + " ";
        }
        sendResponse(raw, source);

        float e0mm = encoderMM_X(encoder0Ticks);
        float e1mm = encoderMM_X(encoder1Ticks);
        float e2mm = encoderMM_Y(encoder2Ticks);
        float e3mm = encoderMM_Y(encoder3Ticks);
        float e4mm = encoderMM_Y(encoder4Ticks);
        float e5mm = encoderMM_Y(encoder5Ticks);
        sendResponse("Encoders: E0=" + String(e0mm, 2) + "mm  E1=" + String(e1mm, 2)
                    + "mm  E2=" + String(e2mm, 2) + "mm  E3=" + String(e3mm, 2)
                    + "mm  E4=" + String(e4mm, 2) + "mm  E5=" + String(e5mm, 2) + "mm", source);

        if (zeroingMode) sendResponse("[JOG & ZERO MODE ACTIVE]", source);
        if (syncAlarm)   sendResponse("[SYNC ALARM ACTIVE]", source);

        sendPositionUpdate(source);
        return;
    }

    // enter jog/zero mode
    if (input == "ZERO" && !zeroingMode) {
        zeroingMode = true;
        if (syncAlarm) syncAlarm = false;
        for (int i = 0; i < numMotors; i++) {
            steppers[i].stop();
            steppers[i].setCurrentPosition(steppers[i].currentPosition());
        }
        sendResponse(">> JOG & ZERO MODE — Jog with M0+/- X+/- Y+/- ZA+/- ZB+/- (ZA=AoA Bot, ZB=AoA Top)", source);
        sendPositionUpdate(source);
        return;
    }

    // jog/zero mode commands
    if (zeroingMode) {
        // individual motor jogs: M0+ M0- M1+ M1- ... M7+ M7-
        if (input.length() >= 3 && input.charAt(0) == 'M') {
            int mNum = input.substring(1, input.length() - 1).toInt();
            char dir = input.charAt(input.length() - 1);
            if (mNum >= 0 && mNum <= 5 && (dir == '+' || dir == '-')) {
                long jogAmount;
                if (mNum <= 1) jogAmount = getJogStepsX();
                else if (mNum <= 5) jogAmount = getJogStepsY();
                else jogAmount = getJogStepsZA();
                long delta = (dir == '+') ? jogAmount : -jogAmount;
                steppers[mNum].move(delta);
                sendResponse(">> Jog M" + String(mNum) + " " + String(dir) + " → " + motorPosStr(mNum), source);
                return;
            }
        }
        // grouped axis jogs: X+ X- Y+ Y- ZA+ ZA- ZB+ ZB-
        if (input == "X+" || input == "X-") {
            long delta = (input.charAt(1) == '+') ? getJogStepsX() : -getJogStepsX();
            steppers[0].move(delta);
            steppers[1].move(delta);
            sendResponse(">> Jog X " + String(input.charAt(1)) + " → " + motorPosStr(0), source);
            return;
        }
        if (input == "Y+" || input == "Y-") {
            long delta = (input.charAt(1) == '+') ? getJogStepsY() : -getJogStepsY();
            for (int i = 2; i <= 5; i++) steppers[i].move(delta);
            sendResponse(">> Jog Y " + String(input.charAt(1)) + " → " + motorPosStr(2), source);
            return;
        }
        if (input == "YL+" || input == "YL-") {
            long delta = (input.charAt(2) == '+') ? getJogStepsY() : -getJogStepsY();
            steppers[2].move(delta);
            steppers[3].move(delta);
            sendResponse(">> Jog Y Left " + String(input.charAt(2)) + " → " + motorPosStr(2), source);
            return;
        }
        if (input == "YR+" || input == "YR-") {
            long delta = (input.charAt(2) == '+') ? getJogStepsY() : -getJogStepsY();
            steppers[4].move(delta);
            steppers[5].move(delta);
            sendResponse(">> Jog Y Right " + String(input.charAt(2)) + " → " + motorPosStr(4), source);
            return;
        }
        if (input == "ZA+" || input == "ZA-") {
            long delta = (input.charAt(2) == '+') ? getJogStepsZA() : -getJogStepsZA();
            steppers[6].move(delta);
            sendResponse(">> Jog AoA Bot " + String(input.charAt(2)) + " → " + motorPosStr(6), source);
            return;
        }
        if (input == "ZB+" || input == "ZB-") {
            long delta = (input.charAt(2) == '+') ? getJogStepsZB() : -getJogStepsZB();
            steppers[7].move(delta);
            sendResponse(">> Jog AoA Top " + String(input.charAt(2)) + " → " + motorPosStr(7), source);
            return;
        }
        // set jog step size
        if (input.startsWith("STEP")) {
            String szStr = input.substring(4);  // string compare avoids float precision issues
            float sz = szStr.toFloat();
            if (szStr == "0.1" || szStr == "0.25" || szStr == "0.5" || szStr == "1.0" || szStr == "1" || szStr == "2.0" || szStr == "2" || szStr == "3.0" || szStr == "3") {
                jogStepMM  = sz;
                jogStepDeg = sz;
                sendResponse(">> Step size: " + String(sz, 2) + "mm / " + String(sz, 2) + "deg", source);
            } else {
                sendResponse("!!! Invalid step. Options: 0.1  0.25  0.5  1.0  2.0  3.0", source);
            }
            return;
        }
        // save current pos as zero
        if (input == "SET") {
            for (int i = 0; i < numMotors; i++) steppers[i].setCurrentPosition(0);
            encoder0Ticks = 0;
            encoder1Ticks = 0;
            encoder2Ticks = 0;
            encoder3Ticks = 0;
            encoder4Ticks = 0;
            encoder5Ticks = 0;
            sendResponse(">> Zero point SET — all positions reset to 0", source);
            sendPositionUpdate(source);
            return;
        }
        // leave without saving
        if (input == "EXIT") {
            zeroingMode = false;
            sendResponse(">> Exited jog & zero mode", source);
            sendPositionUpdate(source);
            return;
        }
        if (input == "COMMANDS") {
            sendResponse("--- JOG & ZERO MODE ---", source);
            sendResponse("Jog: M0+ M0- (X Left)  M1+ M1- (X Right)", source);
            sendResponse("Jog: M2+ M2- (Y Left Close)  M3+ M3- (Y Left Far)", source);
            sendResponse("Jog: M4+ M4- (Y Right Close)  M5+ M5- (Y Right Far)", source);
            sendResponse("Jog groups: X+ X-  Y+ Y-  YL+ YL- (Y Left)  YR+ YR- (Y Right)", source);
            sendResponse("Jog: ZA+ ZA- (AoA Bot)  ZB+ ZB- (AoA Top)", source);
            sendResponse("STEP0.1 STEP0.25 STEP0.5 STEP1.0 STEP2.0 STEP3.0 = set jog increment", source);
            sendResponse("SET = save current pos as zero", source);
            sendResponse("EXIT = leave without saving", source);
            sendResponse("POSITIONS, FAN, ESTOP also available", source);
            return;
        }
        sendResponse("!!! Jog & zero mode — invalid command", source);
        return;
    }

    // normal mode
    if (input == "COMMANDS") {
        sendResponse("--- Airfoil Group Controller ---", source);
        sendResponse("Commands: X[mm], Y[mm], ZA[deg](AoA Bot), ZB[deg](AoA Top), HOME, POSITIONS, COMMANDS, FAN, ESTOP, ZERO, RESUME", source);
        return;
    }
    if (input == "HOME") {
        if (anyMotorMoving()) {
            sendResponse(">> Warning: overriding active move — homing all axes", source);
        }
        sendResponse(">> Homing all axes...", source);
        for(int i = 0; i < numMotors; i++) steppers[i].moveTo(0);
        return;
    }

    int startMotor = -1;
    int endMotor = -1;
    float targetDegrees = 0;
    bool valid = false;
    String axisName = "";

    if (input.startsWith("X")) {
        float mm = input.substring(1).toFloat();
        if (mm > 415 || mm < -415) {
            sendResponse("!!! Out of range, X limit is +/- 415mm", source);
            return;
        }
        startMotor = 0; endMotor = 1;
        targetDegrees = (mm / X_PITCH) * 360.0;
        axisName = "X";
        valid = true;
    } else if (input.startsWith("Y")) {
        float mm = input.substring(1).toFloat();
        if (mm > 225 || mm < -225) {
            sendResponse("!!! Out of range, Y limit is +/- 225mm", source);
            return;
        }
        startMotor = 2; endMotor = 5;
        targetDegrees = (mm / Y_PITCH) * 360.0;
        axisName = "Y";
        valid = true;
    } else if (input.startsWith("ZA")) {
        float deg = input.substring(2).toFloat();
        if (deg > 20 || deg < -20) {
            sendResponse("!!! Out of range, AoA Bot limit is +/- 20deg", source);
            return;
        }
        startMotor = 6; endMotor = 6;
        targetDegrees = deg * ZA_GEAR_RATIO;
        axisName = "AoA Bot";
        valid = true;
    } else if (input.startsWith("ZB")) {
        float deg = input.substring(2).toFloat();
        if (deg > 20 || deg < -20) {
            sendResponse("!!! Out of range, AoA Top limit is +/- 20deg", source);
            return;
        }
        startMotor = 7; endMotor = 7;
        targetDegrees = deg * ZB_GEAR_RATIO;
        axisName = "AoA Top";
        valid = true;
    }

    if (syncAlarm && valid) {
        sendResponse("!!! SYNC ALARM ACTIVE", source);
        return;
    }

    if (valid) {
        // warn if axis still moving
        bool axisBusy = false;
        for (int i = startMotor; i <= endMotor; i++) {
            if (steppers[i].distanceToGo() != 0) { axisBusy = true; break; }
        }
        if (axisBusy) {
            sendResponse(">> Warning: " + axisName + " axis still moving — overriding to new target", source);
        }

        long targetSteps = (targetDegrees / 360.0) * STEPS_PER_REV;
        sendResponse(">> Target Steps: " + String(targetSteps), source);
        for(int i = startMotor; i <= endMotor; i++) {
            steppers[i].moveTo(targetSteps);
        }
    } else if (input.length() > 0) {
        sendResponse("!!! Invalid Command", source);
    }
}
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
void loop() {
    if (Serial.available() > 0) {
        lastSource = SOURCE_USB;
        processCommand(Serial.readStringUntil('\n'), SOURCE_USB);
    }

    if (Serial1.available() > 0) {
        lastSource = SOURCE_BT;
        processCommand(Serial1.readStringUntil('\n'), SOURCE_BT);
    }

    bool moving = false;

    if (!syncAlarm) {
        for(int i = 0; i < numMotors; i++) {
            steppers[i].run();
            if (steppers[i].distanceToGo() != 0) moving = true;
        }

        // x sync check (skipped in jog mode)
        bool xMoving = (steppers[0].distanceToGo() != 0) || (steppers[1].distanceToGo() != 0);
        if (xMoving && !zeroingMode) {
            float e0mm = encoderMM_X(encoder0Ticks);
            float e1mm = encoderMM_X(encoder1Ticks);
            float diff = abs(e0mm - e1mm);

            if (diff > X_SYNC_THRESHOLD_MM) {
                for (int i = 0; i < numMotors; i++) {
                    steppers[i].stop();
                    steppers[i].setCurrentPosition(steppers[i].currentPosition());
                }
                syncAlarm = true;
                alarmSource = "X";
                sendResponse("!!! SYNC ALARM X — E0=" + String(e0mm, 2) + "mm E1=" + String(e1mm, 2) + "mm (diff=" + String(diff, 2) + "mm)", lastSource);
                sendPositionUpdate(lastSource);
                // drop into jog mode for realignment
                syncAlarm = false;  // clear alarm so jog mode works
                zeroingMode = true;
                sendResponse(">> Entering JOG & ZERO MODE — realign motors, then EXIT to resume", lastSource);
            }
        }

        // y sync check (skipped in jog mode)
        bool yMoving = (steppers[2].distanceToGo() != 0) || (steppers[3].distanceToGo() != 0)
                    || (steppers[4].distanceToGo() != 0) || (steppers[5].distanceToGo() != 0);
        if (yMoving && !zeroingMode && !syncAlarm) {
            float e2mm = encoderMM_Y(encoder2Ticks);
            float e3mm = encoderMM_Y(encoder3Ticks);
            float e4mm = encoderMM_Y(encoder4Ticks);
            float e5mm = encoderMM_Y(encoder5Ticks);

            float yVals[4] = { e2mm, e3mm, e4mm, e5mm };
            float yMax = yVals[0], yMin = yVals[0];
            for (int i = 1; i < 4; i++) {
                if (yVals[i] > yMax) yMax = yVals[i];
                if (yVals[i] < yMin) yMin = yVals[i];
            }
            float diff = yMax - yMin;

            if (diff > Y_SYNC_THRESHOLD_MM) {
                for (int i = 0; i < numMotors; i++) {
                    steppers[i].stop();
                    steppers[i].setCurrentPosition(steppers[i].currentPosition());
                }
                syncAlarm = true;
                alarmSource = "Y";
                sendResponse("!!! SYNC ALARM Y — E2=" + String(e2mm, 2) + "mm E3=" + String(e3mm, 2) + "mm E4=" + String(e4mm, 2) + "mm E5=" + String(e5mm, 2) + "mm (diff=" + String(diff, 2) + "mm)", lastSource);
                sendPositionUpdate(lastSource);
                // drop into jog mode for realignment
                syncAlarm = false;  // clear alarm so jog mode works
                zeroingMode = true;
                sendResponse(">> Entering JOG & ZERO MODE — realign motors, then EXIT to resume", lastSource);
            }
        }
    } else {
        moving = false;
    }

    // auto-send pos update on motion complete (skip in jog mode)
    static bool wasMoving = false;
    if (!moving && wasMoving) {
        if (!zeroingMode) {
            sendResponse("--- Motion Complete. ---", lastSource);
            sendPositionUpdate(lastSource);
        }
    }
    wasMoving = moving;
}

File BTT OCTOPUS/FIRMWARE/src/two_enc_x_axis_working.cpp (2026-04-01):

#include <Arduino.h>
#include <AccelStepper.h>

// --- MOTOR DEFINITIONS ---
#define ENABLE_PIN0 PF14
#define STEP_PIN0   PF13
#define DIR_PIN0    PF12

#define ENABLE_PIN1 PF15
#define STEP_PIN1   PG0
#define DIR_PIN1    PG1

#define ENABLE_PIN2 PG5
#define STEP_PIN2   PF11
#define DIR_PIN2    PG3

#define ENABLE_PIN3 PA0
#define STEP_PIN3   PG4
#define DIR_PIN3    PC1

#define ENABLE_PIN4 PG2
#define STEP_PIN4   PF9
#define DIR_PIN4    PF10

#define ENABLE_PIN5 PF1
#define STEP_PIN5   PC13
#define DIR_PIN5    PF0

#define ENABLE_PIN6 PD4
#define STEP_PIN6   PE2
#define DIR_PIN6    PE3

#define ENABLE_PIN7 PE0
#define STEP_PIN7   PE6
#define DIR_PIN7    PA14

// --- FAN DEFINITIONS ---
#define FAN0_PIN    PA8  
bool fanOn = true;

// --- ENCODER DEFINITIONS ---
#define EA1plus     PG6
#define EB1plus     PG9
#define EA2plus     PG10
#define EB2plus     PG11

const float PULSES_PER_REV = 2000.0; 
volatile long encoder1Ticks = 0;
volatile long encoder2Ticks = 0;

// --- MOTION SETTINGS ---
const int MICROSTEP_SETTING = 8;     
const long STEPS_PER_REV = 200 * MICROSTEP_SETTING;
const float X_PITCH = 5.0; 
const float Y_PITCH = 2.0; 

// --- ACCELSTEPPER OBJECTS ---
AccelStepper steppers[] = {
    AccelStepper(AccelStepper::DRIVER, STEP_PIN0, DIR_PIN0),
    AccelStepper(AccelStepper::DRIVER, STEP_PIN1, DIR_PIN1),
    AccelStepper(AccelStepper::DRIVER, STEP_PIN2, DIR_PIN2),
    AccelStepper(AccelStepper::DRIVER, STEP_PIN3, DIR_PIN3),
    AccelStepper(AccelStepper::DRIVER, STEP_PIN4, DIR_PIN4),
    AccelStepper(AccelStepper::DRIVER, STEP_PIN5, DIR_PIN5),
    AccelStepper(AccelStepper::DRIVER, STEP_PIN6, DIR_PIN6),
    AccelStepper(AccelStepper::DRIVER, STEP_PIN7, DIR_PIN7)
};

const int numMotors = 8;
int enPins[] = {ENABLE_PIN0, ENABLE_PIN1, ENABLE_PIN2, ENABLE_PIN3, ENABLE_PIN4, ENABLE_PIN5, ENABLE_PIN6, ENABLE_PIN7};

enum InputSource { SOURCE_NONE, SOURCE_USB, SOURCE_BT };
InputSource lastSource = SOURCE_NONE;

// --- ISRs ---
void handleEncoder1() {
    if (digitalRead(EA1plus) == digitalRead(EB1plus)) encoder1Ticks++; else encoder1Ticks--;
}

void handleEncoder2() {
    if (digitalRead(EA2plus) == digitalRead(EB2plus)) encoder2Ticks++; else encoder2Ticks--;
}

void sendResponse(const String& msg, InputSource source) {
    if (source == SOURCE_USB || source == SOURCE_NONE) Serial.println(msg);
    if (source == SOURCE_BT || source == SOURCE_NONE) Serial1.println(msg);
}

void processCommand(String input, InputSource source) {
    input.trim();
    input.toUpperCase();

    int startMotor = -1;
    int endMotor = -1;
    float targetDegrees = 0;
    bool valid = false;

    if (input == "STATUS") {
        String status = "Positions: ";
        for(int i = 0; i < numMotors; i++) {
            status += "M" + String(i) + "=" + String(steppers[i].currentPosition()) + " ";
        }
        sendResponse(status, source);
        
        float angle1 = (static_cast<float>(encoder1Ticks) / PULSES_PER_REV) * 360.0;
        float angle2 = (static_cast<float>(encoder2Ticks) / PULSES_PER_REV) * 360.0;
        sendResponse("Encoders: E1=" + String(angle1, 2) + " E2=" + String(angle2, 2), source);
        return;
    } 
    
    if (input == "HOME") {
        sendResponse(">> Homing...", source);
        for(int i = 0; i < numMotors; i++) steppers[i].moveTo(0);
        return;
    } 
    
    if (input.startsWith("X")) {
        startMotor = 0; endMotor = 1;
        targetDegrees = (input.substring(1).toFloat() / X_PITCH) * 360.0;
        valid = true;
    } else if (input.startsWith("Y")) {
        startMotor = 2; endMotor = 5;
        targetDegrees = (input.substring(1).toFloat() / Y_PITCH) * 360.0;
        valid = true;
    } else if (input.startsWith("ZA")) {
        startMotor = 6; endMotor = 6;
        targetDegrees = input.substring(2).toFloat() * 5.197539843600339;
        valid = true;
    } else if (input.startsWith("ZB")) {
        startMotor = 7; endMotor = 7;
        targetDegrees = input.substring(2).toFloat() * 5.197539843600339;
        valid = true;
    } else if (input == "STOP") {
        for(int i = 0; i < numMotors; i++) {
            steppers[i].stop();
            steppers[i].setCurrentPosition(steppers[i].currentPosition());
        }
        sendResponse(">> STOPPED", source);
        return;
    } else if (input == "FAN") {
        fanOn = !fanOn;
        digitalWrite(FAN0_PIN, fanOn ? HIGH : LOW);
        sendResponse(fanOn ? ">> Fan ON" : ">> Fan OFF", source);
        return;
    }

    if (valid) {
        long targetSteps = (targetDegrees / 360.0) * STEPS_PER_REV;
        sendResponse(">> Target: " + String(targetSteps), source);
        for(int i = startMotor; i <= endMotor; i++) steppers[i].moveTo(targetSteps);
    }
}

void setup() {
    Serial.begin(115200);
    Serial1.begin(115200); // Set back to 115200 for HC-05

    pinMode(FAN0_PIN, OUTPUT);
    digitalWrite(FAN0_PIN, HIGH); 

    for(int i = 0; i < numMotors; i++) {
        pinMode(enPins[i], OUTPUT);
        digitalWrite(enPins[i], LOW); 
        steppers[i].setMaxSpeed(5000);   
        steppers[i].setAcceleration(1000); 
    }

    pinMode(EA1plus, INPUT_PULLUP);
    pinMode(EB1plus, INPUT_PULLUP);
    attachInterrupt(digitalPinToInterrupt(EA1plus), handleEncoder1, CHANGE);

    pinMode(EA2plus, INPUT_PULLUP);
    pinMode(EB2plus, INPUT_PULLUP);
    attachInterrupt(digitalPinToInterrupt(EA2plus), handleEncoder2, CHANGE);

    delay(2000);
    sendResponse("--- System Ready (Dual Encoders) ---", SOURCE_NONE);
}

void loop() {
    if (Serial.available() > 0) {
        lastSource = SOURCE_USB;
        processCommand(Serial.readStringUntil('\n'), SOURCE_USB);
    }
    
    if (Serial1.available() > 0) {
        lastSource = SOURCE_BT;
        processCommand(Serial1.readStringUntil('\n'), SOURCE_BT);
    }

    bool moving = false;
    for(int i = 0; i < numMotors; i++) {
        steppers[i].run();
        if (steppers[i].distanceToGo() != 0) moving = true;
    }

    static bool wasMoving = false;
    if (!moving && wasMoving) {
        sendResponse("--- Motion Complete. ---", lastSource);
    }
    wasMoving = moving;
}

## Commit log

2026-01-14 EncoderGivingValues
    The motors would move and the encoder would give values. The encoder values were roughly 3 times as high as they should've been.
2026-01-31 Encoder accurate +/- 2 degree
    Motor logic commented. Worried that it is blocking encoder from updating when rotating it too fast...
    [main.cpp]
2026-01-31 Rotate 180 degrees in 3 seconds with good accuracy
    Motor now runs 180 degrees in 3 seconds, the encoder is very accurate.
2026-02-02 Set desired angle for motor
    Motor will work, but is stuck moving in increments of 1.8 deg
    [main.cpp]
2026-02-20 GROUPED MOTOR MOVEMENT
    Motors now selectable by group and home all feature works.
2026-02-27 made AoA motors accurate
    Much accuracy
2026-03-06 We're stuck
    Board is fried (?)
2026-03-16 New board, fan working
    New board set up, fan working
2026-03-23 New board here and running
    Many updates
2026-04-08 renaming
    organize
    [zero-tool.SLDPRT]
2026-04-10 working, wind tunnel test worked
    Working, successfully used in the wind tunnel for Yang's thermal fluids lab
    [Airfoil 2.3MF, Airfoil 2.STL, zero-tool.SLDPRT]
2026-04-15 Pre- AMT25 install
    Have working test / isolated code for the new AMT25 encoders, it has not been tested yet though.
2026-04-15 Waiting to integrate 2x AMT25 abs. encoders
    Patch
2026-04-20 waiting to test 2x amt25 encoders
2026-04-23 GUI prettier
    ✈
